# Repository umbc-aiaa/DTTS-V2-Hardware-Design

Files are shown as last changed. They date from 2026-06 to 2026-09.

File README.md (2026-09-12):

# DTTS V2

This repo houses the hardware design and associated documentation for the SUAS Dynamic Thrust Test Stand(DTTS) V2.
The new board is designed to be more intuitive to use and more robust against failures like over voltage, shorts, etc.
The V2 board also integrates all sensors and ICs in a single solution.



## System Diagram
```mermaid
graph LR;
LC[<b>Load Cell</b></br>Uses a Wheatstone Bridge to provide a differential voltage signal to the ADC.];
CS[<b>Current Sensor</b></br>Current sensing is implemented with a shunt resistor with differential input feeding into the ADC.];
VS[<b>Voltage Sensor</b></br>Voltage sensing circuit is implemented as a simple resistor voltage divider.];
ADC["<b>Analog-to-Digital Converter (ADC)</b></br>Converts single mode and differential analog signals into a digital format."];
MC[<b>ESP32 S3 WROOM 1</b></br>Controls esc for the motor, collects measurements, and communcates them over WiFi.];
ESC[<b>Electronic Speed Controller</b><br />Converts DC from battery to 3-phase AC for motor.]

GUI[<b>Front End UI</b></br>A front end GUI collects measurements and makes user interaction simple.];

LC --> ADC;
CS --> ADC;
VS --> ADC;

ADC --> MC;

MC -- PWM --> ESC;

GUI <== WiFi ==> MC;

ADC ~~~ GUI;
```

## Working Specs
- Battery Voltage $\leq$ 50 V.
- Max ESC Current $\leq$ 90 A.
- Using 6 AWG wire for battery.
- Must at minimum measure battery voltage, batter to ESC current, and Motor Thrust
- All circuitry must run off of a single battery -- the one plugged into the ESC
- Preferable to have auto-trimming and gain calibration on voltage sense circuity.

## Component Selection (Draft!)

### Power Supply
There are some different approaches to this. If we were using a seperate battery for this, then we could have just used a linear regulator, but if we want to use the motor battery, this voltage may range from 12 to 60 V. So we probably need to use a buck converter. We could also use a hybrid design (i.e. 12-60V input down to 4.5V with a buck converter and 4.5V to 3.3V with an LDO). This may complicate things a little, but it's a very good choice in terms of noise and is also fairly efficient.

1. ~~[Diodes Incorporated AP66200](https://www.diodes.com/assets/Datasheets/AP66200.pdf) Buck controller.~~
2. [TI LMR51625](https://www.ti.com/lit/ds/symlink/lmr51625.pdf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) Buck Controller (preferred).
  a. Also, if using TI ICs for power conversion, check out [Webench Designer](https://webench.ti.com/power-designer/)

**All regulated power rails must have a zener diode of appropriate voltage to pull lines down if they have too high of a voltage.**
We should run some simulations to ensure the zener diode is enough for protecting regulated lines if battery is shorted to them or if
we need to have something else. We may also want to consider adding a fuse to the power rail since the zener diode will short to ground
and pull a lot of current.

## Voltage Protection on Signal Pins
For signal pins, zener diodes may work, but there are options for more precise control like Schottkey diodes. These can also provide reverse polarity protection if configured correctly, so this is the solution we will use. Here are some options for diodes that may work. The Rohm diode has a lower forward drop, which is good for protecting against over-voltage, but it has a low reverse voltage rating which is worse for reverse-polarity protection. The opposite is true for the Toshiba diode. We may need to look for other diodes that have the adequate reverse voltage rating(60V) and a low drop(ideally $\leq$ 300mV).
1. [Toshiba CUS10S30 Schottkey Diodes](https://toshiba.semicon-storage.com/info/CUS10S30_datasheet_en_20140407.pdf?did=14077&prodName=CUS10S30) for signal over-voltage protection.\
  a. [Rohm RB520CM-60 Schottkey Diode](https://fscdn.rohm.com/en/products/databook/datasheet/discrete/diode/schottky_barrier/rb520cm-60t2r-e.pdf) Alternative to (1) with higher reverse voltage

### Analog to Digital Converter
This component converts analog voltages(i.e. voltages that are not strictly interpretted as a `0` or a `1`) into a digital format(i.e. `0`'s and `1`'s). This allows software on the esp32 to read and store analog voltages as numbers or percents and communicate these values over WiFi or another transport medium to the GUI for the user. Since we are using a load cell, this needs a sensative ADC, and hence we choose to use a 24-bit chip. These are some options worth considering:

1. [Microchip MCP3564R](https://ww1.microchip.com/downloads/aemDocuments/documents/APID/ProductDocuments/DataSheets/MCP3561_2_4R-Data-Sheet-DS200006391C.pdf) has four channels, meaning we can use this for all three sensors (battery voltage, battery current, and motor thrust).

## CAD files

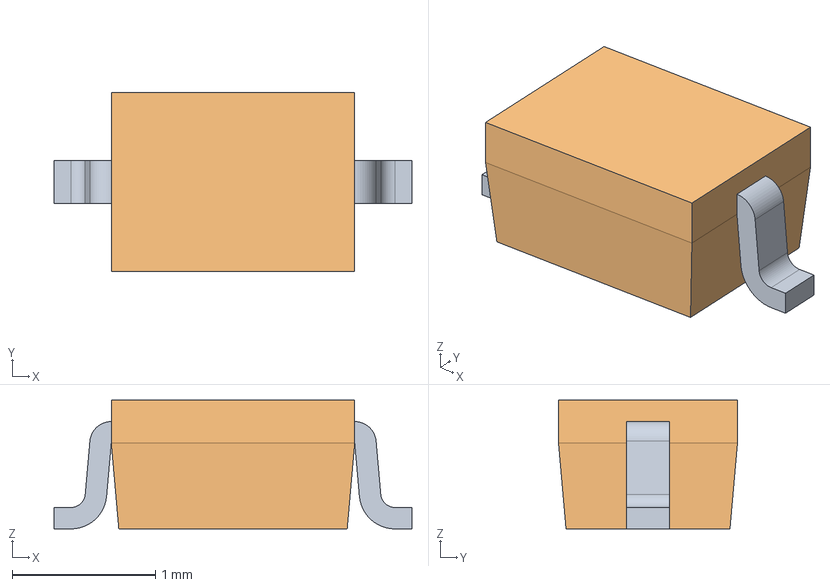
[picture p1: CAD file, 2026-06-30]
CUS520_H3F/USC-ZKN_r.stp
2.50 x 1.25 x 0.9 mm

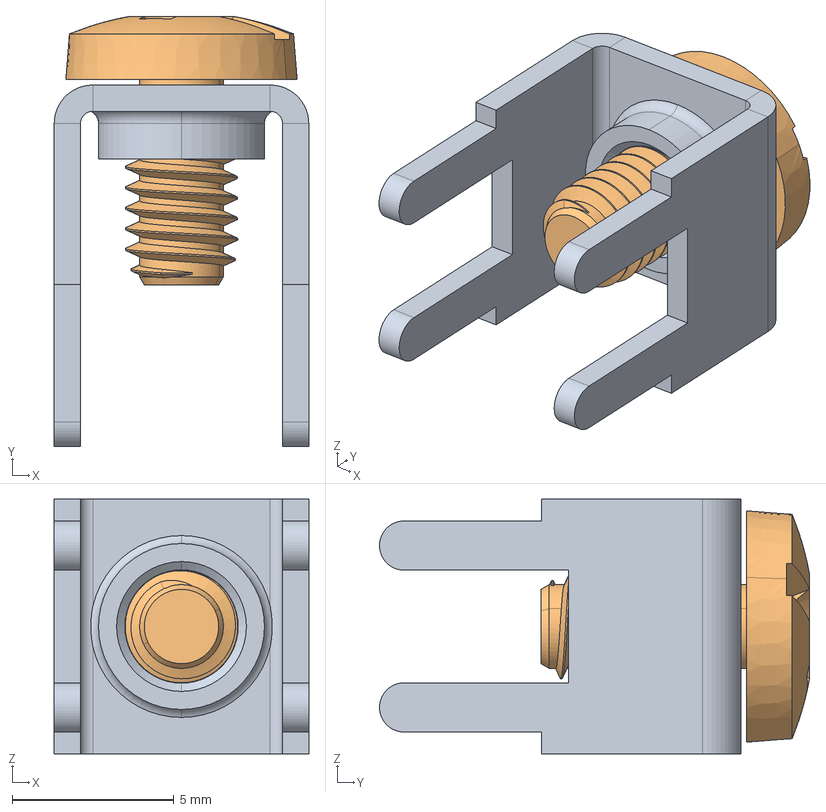
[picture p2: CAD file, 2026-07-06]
Keystone 7771-7771.step
7.87 x 13.3 x 7.87 mm

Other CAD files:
CUS520_H3F/USC-ZKN_r.stl

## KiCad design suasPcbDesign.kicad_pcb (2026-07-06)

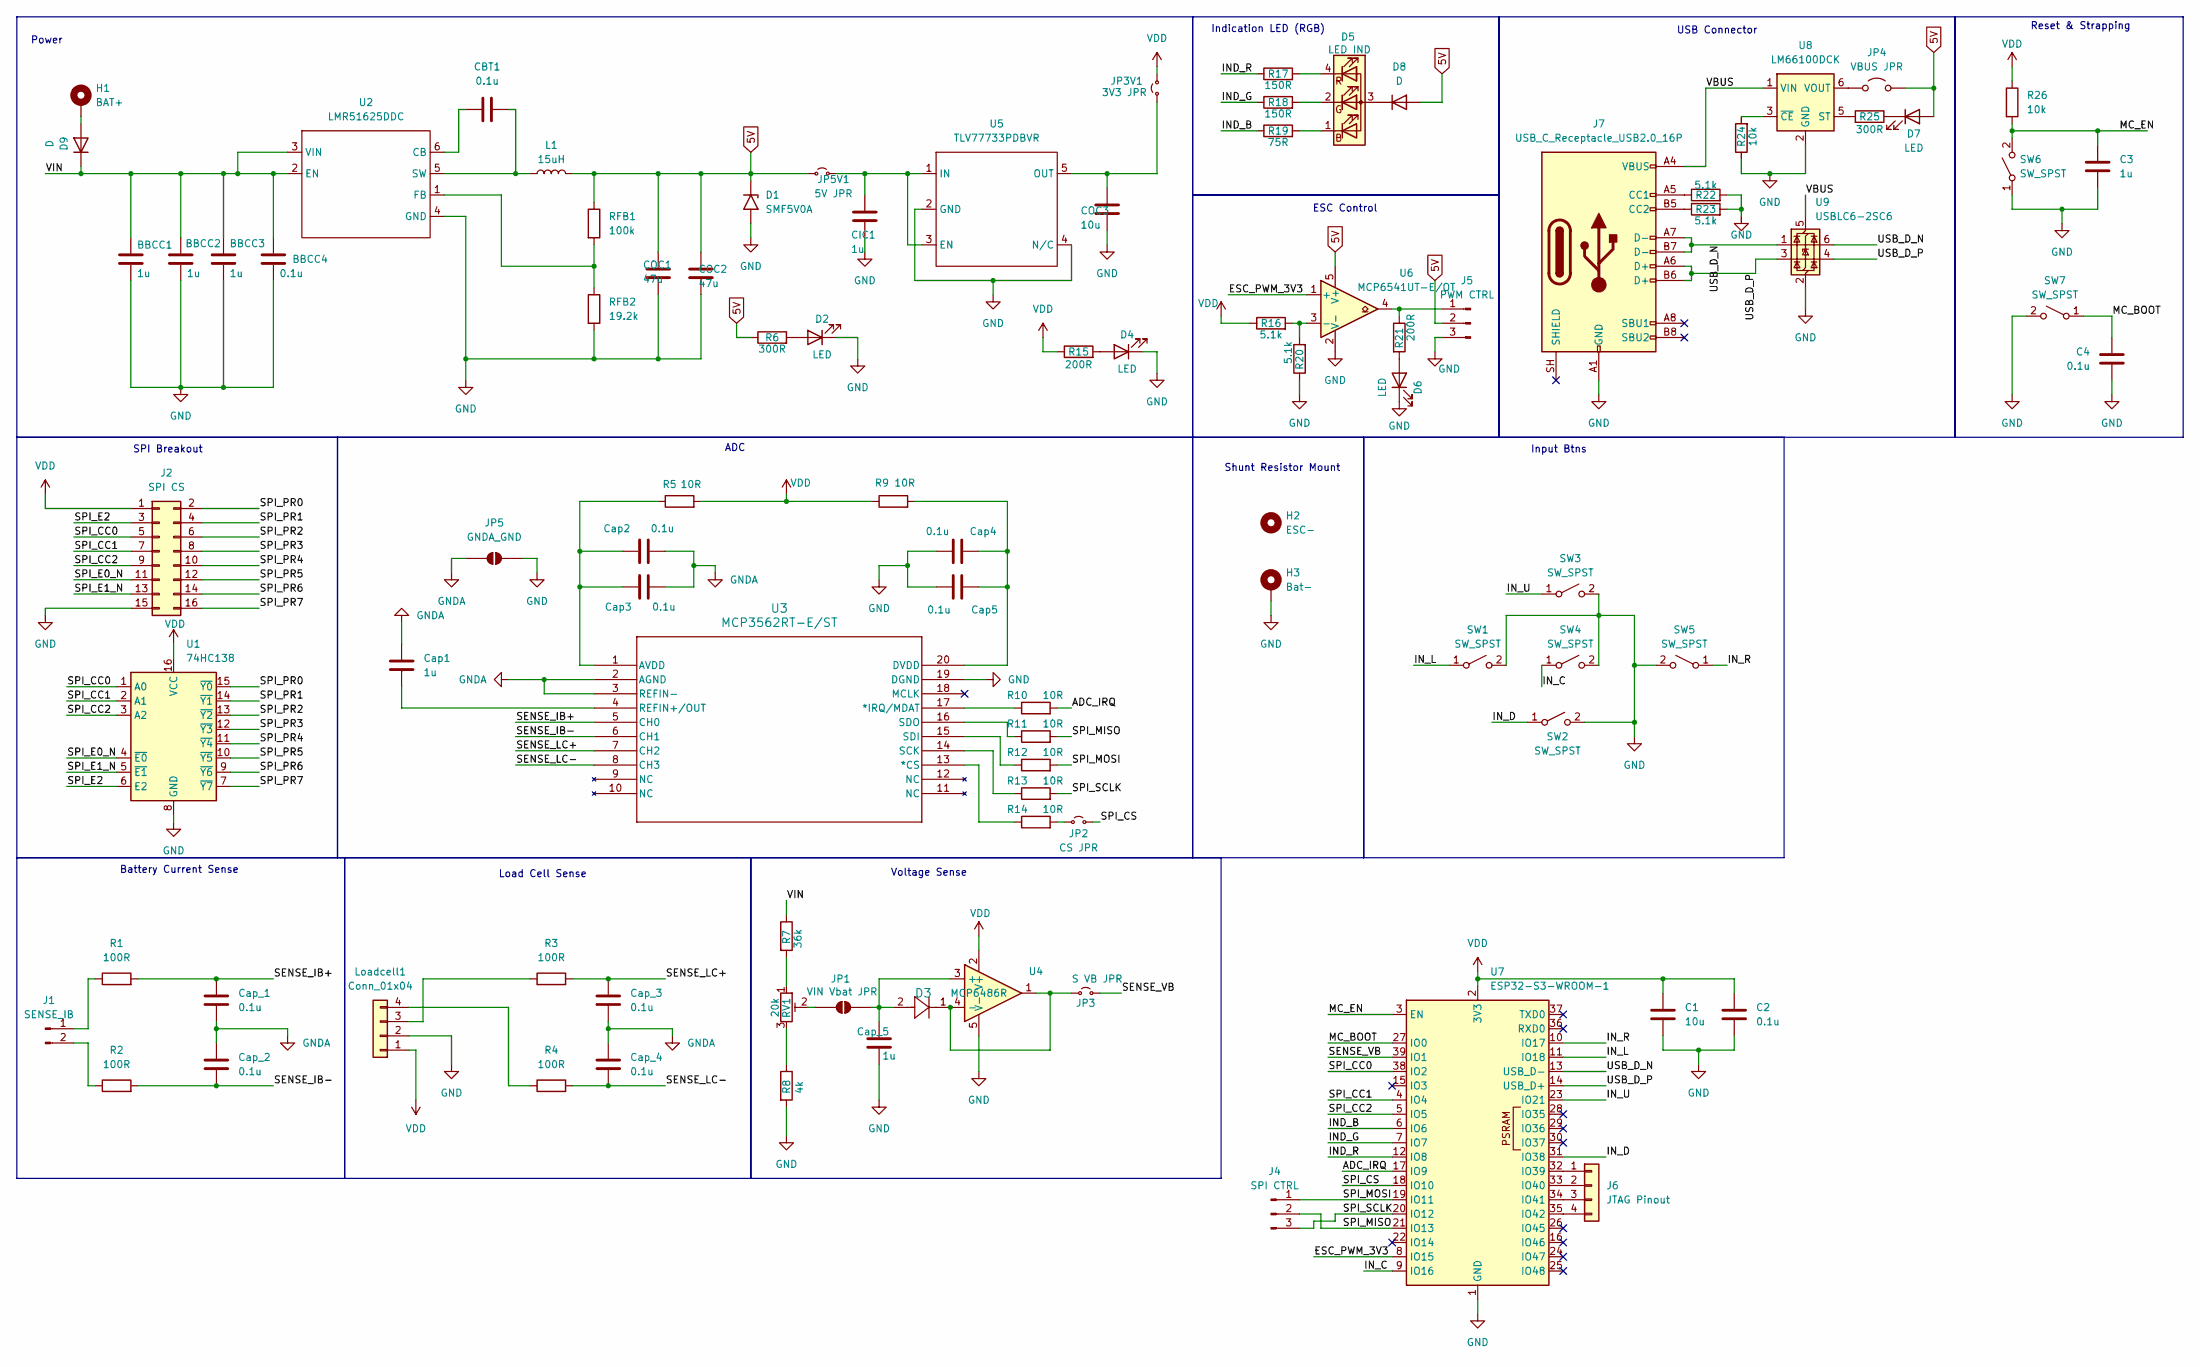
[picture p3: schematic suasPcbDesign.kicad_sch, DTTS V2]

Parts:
BBCC1, BBCC2, BBCC3: 1u; C_0603_1608Metric_Pad1.08x0.95mm_HandSolder
BBCC4: 0.1u; C_0603_1608Metric_Pad1.08x0.95mm_HandSolder
C1: 10u; C_0603_1608Metric_Pad1.08x0.95mm_HandSolder
C2, C4: 0.1u; C_0603_1608Metric_Pad1.08x0.95mm_HandSolder
C3: 1u; C_0603_1608Metric_Pad1.08x0.95mm_HandSolder
CBT1: 0.1u; C_0603_1608Metric_Pad1.08x0.95mm_HandSolder
CIC1: 1u; C_0603_1608Metric_Pad1.08x0.95mm_HandSolder
COC1, COC2: 47u; C_0603_1608Metric_Pad1.08x0.95mm_HandSolder
COC3: 10u; C_0603_1608Metric_Pad1.08x0.95mm_HandSolder
Cap1: 1u; C_0603_1608Metric_Pad1.08x0.95mm_HandSolder
Cap2, Cap3, Cap4, Cap5: 0.1u; C_0603_1608Metric_Pad1.08x0.95mm_HandSolder
Cap_1, Cap_2, Cap_3, Cap_4: 0.1u; C_0603_1608Metric_Pad1.08x0.95mm_HandSolder
Cap_5: 1u; C_0603_1608Metric_Pad1.08x0.95mm_HandSolder
D1: SMF5V0A; D_SOD-123
D2, D4, D6, D7: LED; LED_0603_1608Metric_Pad1.05x0.95mm_HandSolder
D3: CUS520_H3F; USC_TOS
D5: LED IND; LED_D5.0mm-4_RGB
D8, D9: D; D_SMA-SMB_Universal_Handsoldering
H1: BAT+; 7770 Keystone Electronics PC SCREW TERMINALS
H2: ESC-; MountingHole_6.3mm_M6_DIN965
H3: Bat-; MountingHole_6.3mm_M6_Pad_Via
J1: SENSE_IB; SolderWire-1sqmm_1x02_P5.4mm_D1.4mm_OD2.7mm
J2: SPI CS; PinHeader_2x08_P2.54mm_Vertical
J4: SPI CTRL; PinHeader_1x03_P2.54mm_Vertical
J5: PWM CTRL; PinHeader_1x03_P2.54mm_Vertical
J6: JTAG Pinout; PinHeader_1x04_P2.54mm_Vertical
J7: USB_C_Receptacle_USB2.0_16P; USB_C_Receptacle_GCT_USB4105-xx-A_16P_TopMnt_Horizontal
JP1: VIN Vbat JPR; SolderJumper-2_P1.3mm_Open_Pad1.0x1.5mm
JP2: CS JPR; TestPoint_2Pads_Pitch2.54mm_Drill0.8mm
JP3: S VB JPR; TestPoint_2Pads_Pitch2.54mm_Drill0.8mm
JP3V1: 3V3 JPR; TestPoint_2Pads_Pitch2.54mm_Drill0.8mm
JP4: VBUS JPR; TestPoint_2Pads_Pitch2.54mm_Drill0.8mm
JP5: GNDA_GND; SolderJumper-2_P1.3mm_Open_Pad1.0x1.5mm
JP5V1: 5V JPR; TestPoint_2Pads_Pitch2.54mm_Drill0.8mm
L1: 15uH; L_APV_APH1050
Loadcell1: Conn_01x04; PinHeader_1x04_P2.54mm_Vertical
R1, R2, R3, R4: 100R; R_0603_1608Metric_Pad0.98x0.95mm_HandSolder
R5, R9, R10, R11, R12, R13, R14: 10R; R_0603_1608Metric_Pad0.98x0.95mm_HandSolder
R6, R25: 300R; R_0603_1608Metric_Pad0.98x0.95mm_HandSolder
R7: 36k; R_0603_1608Metric_Pad0.98x0.95mm_HandSolder
R8: 4k; R_0603_1608Metric_Pad0.98x0.95mm_HandSolder
R15, R21: 200R; R_0603_1608Metric_Pad0.98x0.95mm_HandSolder
R16, R20, R22, R23: 5.1k; R_0603_1608Metric_Pad0.98x0.95mm_HandSolder
R17, R18: 150R; R_0603_1608Metric_Pad0.98x0.95mm_HandSolder
R19: 75R; R_0603_1608Metric_Pad0.98x0.95mm_HandSolder
R24, R26: 10k; R_0603_1608Metric_Pad0.98x0.95mm_HandSolder
RFB1: 100k; R_0603_1608Metric_Pad0.98x0.95mm_HandSolder
RFB2: 19.2k; R_0603_1608Metric_Pad0.98x0.95mm_HandSolder
RV1: 20k; Potentiometer_Bourns_3386P_Vertical
SW1, SW2, SW3, SW4, SW5, SW6, SW7: SW_SPST; SW_PUSH_1P1T_6x3.5mm_H4.3_APEM_MJTP1243
U1: 74HC138; TSSOP-16_4.4x5mm_P0.65mm
U2: LMR51625DDC; TSOT-23-6_HandSoldering
U3: MCP3562RT-E/ST; TSSOP-20_4.4x6.5mm_P0.65mm
U4: MCP6486R; SOT-23-5_HandSoldering
U5: TLV77733PDBVR; SOT-23-5_HandSoldering
U6: MCP6541UT-E/OT; SOT-23-5_HandSoldering
U7: ESP32-S3-WROOM-1
U8: LM66100DCK; SOT-363_SC-70-6
U9: USBLC6-2SC6; SOT-23-6

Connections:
5V: COC1.1, COC2.1, D1.1 (A1), D7.2 (A), D8.2 (A), J5.2, JP4.2 (B), JP5V1.1 (A), L1.2, R6.1, RFB1.1, U6.5 (V+)
/ADC_IRQ: R10.2, U7.17 (IO9)
/ESC_PWM_3V3: U6.1 (+), U7.8 (IO15)
/IND_B: R19.1, U7.6 (IO6)
/IND_G: R18.1, U7.7 (IO7)
/IND_R: R17.1, U7.12 (IO8)
/IN_C: SW4.1 (A), U7.9 (IO16)
/IN_D: SW2.1 (A), U7.31 (IO38)
/IN_L: SW1.1 (A), U7.11 (IO18)
/IN_R: SW5.1 (A), U7.10 (IO17)
/IN_U: SW3.1 (A), U7.23 (IO21)
/MC_BOOT: C4.1, SW7.1 (A), U7.27 (IO0)
/MC_EN: C3.1, R26.2, SW6.2 (B), U7.3 (EN)
/SENSE_IB+: Cap_1.1, R1.2, U3.5 (CH0)
/SENSE_IB-: Cap_2.2, R2.2, U3.6 (CH1)
/SENSE_LC+: Cap_3.1, R3.2, U3.7 (CH2)
/SENSE_LC-: Cap_4.2, R4.2, U3.8 (CH3)
/SENSE_VB: JP3.2 (B), U7.39 (IO1)
/SPI_CC0: J2.5, U1.1 (A0), U7.38 (IO2)
/SPI_CC1: J2.7, U1.2 (A1), U7.4 (IO4)
/SPI_CC2: J2.9, U1.3 (A2), U7.5 (IO5)
/SPI_CS: JP2.2 (B), U7.18 (IO10)
/SPI_E0_N: J2.11, U1.4 (~E0)
/SPI_E1_N: J2.13, U1.5 (~E1)
/SPI_E2: J2.3, U1.6 (E2)
/SPI_MISO: J4.2, R11.2, U7.21 (IO13)
/SPI_MOSI: J4.1, R12.2, U7.19 (IO11)
/SPI_PR0: J2.2, U1.15 (~Y0)
/SPI_PR1: J2.4, U1.14 (~Y1)
/SPI_PR2: J2.6, U1.13 (~Y2)
/SPI_PR3: J2.8, U1.12 (~Y3)
/SPI_PR4: J2.10, U1.11 (~Y4)
/SPI_PR5: J2.12, U1.10 (~Y5)
/SPI_PR6: J2.14, U1.9 (~Y6)
/SPI_PR7: J2.16, U1.7 (~Y7)
/SPI_SCLK: J4.3, R13.2, U7.20 (IO12)
/USB_D_N: J7.A7 (D-), J7.B7 (D-), U7.13 (USB_D-), U9.1 (I/O1), U9.6 (I/O1)
/USB_D_P: J7.A6 (D+), J7.B6 (D+), U7.14 (USB_D+), U9.3 (I/O2), U9.4 (I/O2)
/VBUS: J7.A4 (VBUS), J7.A9 (VBUS), J7.B4 (VBUS), J7.B9 (VBUS), U8.1 (VIN), U9.5 (VBUS)
/VIN: BBCC1.1, BBCC2.1, BBCC3.1, BBCC4.1, D9.1 (K), R7.1, U2.2 (EN), U2.3 (VIN)
GND: BBCC1.2, BBCC2.2, BBCC3.2, BBCC4.2, C1.2, C2.2, C3.2, C4.2, CIC1.2, COC1.2, COC2.2, COC3.2, Cap4.2, Cap5.2, Cap_5.2, D1.2 (A2), D2.1 (K), D4.1 (K), D6.1 (K), H3.1 (1_1), J2.15, J5.3, J7.A1 (GND), J7.A12 (GND), J7.B1 (GND), J7.B12 (GND), JP5.2 (B), Loadcell1.2, R8.2, R20.1, R22.2, R23.2, R24.1, RFB2.2, SW1.2 (B), SW2.2 (B), SW3.2 (B), SW4.2 (B), SW5.2 (B), SW6.1 (A), SW7.2 (B), U1.8 (GND), U2.4 (GND), U3.19 (DGND), U4.5 (V-), U5.2 (GND), U5.4 (N/C), U6.2 (V-), U7.1 (GND), U7.40 (GND), U7.41 (GND), U8.2 (GND), U9.2 (GND)
GNDA: Cap1.2, Cap2.2, Cap3.2, Cap_1.2, Cap_2.1, Cap_3.2, Cap_4.1, JP5.1 (A), U3.2 (AGND), U3.3 (REFIN-)
unnamed: D2.2 (A), R6.2
unnamed: D4.2 (A), R15.2
unnamed: D5.3 (A), D8.1 (K)
unnamed: D5.1 (BK), R19.2
unnamed: D5.2 (GK), R18.2
unnamed: D5.4 (RK), R17.2
unnamed: D6.2 (A), R21.2
unnamed: D7.1 (K), R25.1
unnamed: D9.2 (A), H1.1 (1_1)
unnamed: J1.1, R1.1
unnamed: J1.2, R2.1
unnamed: J5.1, R21.1, U6.4
unnamed: J6.1, U7.32 (IO39)
unnamed: J6.2, U7.33 (IO40)
unnamed: J6.3, U7.34 (IO41)
unnamed: J6.4, U7.35 (IO42)
unnamed: J7.A5 (CC1), R22.1
unnamed: J7.B5 (CC2), R23.1
unnamed: JP1.1 (A), RV1.2
unnamed: Cap_5.1, D3.2, JP1.2 (B), U4.3 (+)
unnamed: JP2.1 (A), R14.2
unnamed: D3.1, JP3.1 (A), U4.1, U4.4 (-)
unnamed: COC3.1, JP3V1.1 (A), U5.5 (OUT)
unnamed: JP4.1 (A), U8.6 (VOUT)
unnamed: CIC1.1, JP5V1.2 (B), U5.1 (IN), U5.3 (EN)
unnamed: Loadcell1.3, R3.1
unnamed: Loadcell1.4, R4.1
unnamed: R7.2, RV1.1
unnamed: R8.1, RV1.3
unnamed: CBT1.1, U2.6 (CB)
unnamed: RFB1.2, RFB2.1, U2.1 (FB)
unnamed: CBT1.2, L1.1, U2.5 (SW)
unnamed: R14.1, U3.13 (*CS)
unnamed: R10.1, U3.17 (*IRQ/MDAT)
unnamed: Cap2.1, Cap3.1, R5.1, U3.1 (AVDD)
unnamed: Cap4.1, Cap5.1, R9.2, U3.20 (DVDD)
unnamed: Cap1.1, U3.4 (REFIN+/OUT)
unnamed: R13.1, U3.14 (SCK)
unnamed: R12.1, U3.15 (SDI)
unnamed: R11.1, U3.16 (SDO)
unnamed: R16.2, R20.2, U6.3 (-)
unnamed: R25.2, U8.5 (ST)
unnamed: R24.2, U8.3 (~CE)
VDD: C1.1, C2.1, J2.1, JP3V1.2 (B), Loadcell1.1, R5.2, R9.1, R15.1, R16.1, R26.1, U1.16 (VCC), U4.2 (V+), U7.2 (3V3)

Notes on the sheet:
SPI Breakout
Reset & Strapping
Voltage Sense
ESC Control
Shunt Resistor Mount
Load Cell Sense
Input Btns
Battery Current Sense
Power
Indication LED (RGB)
ADC
USB Connector

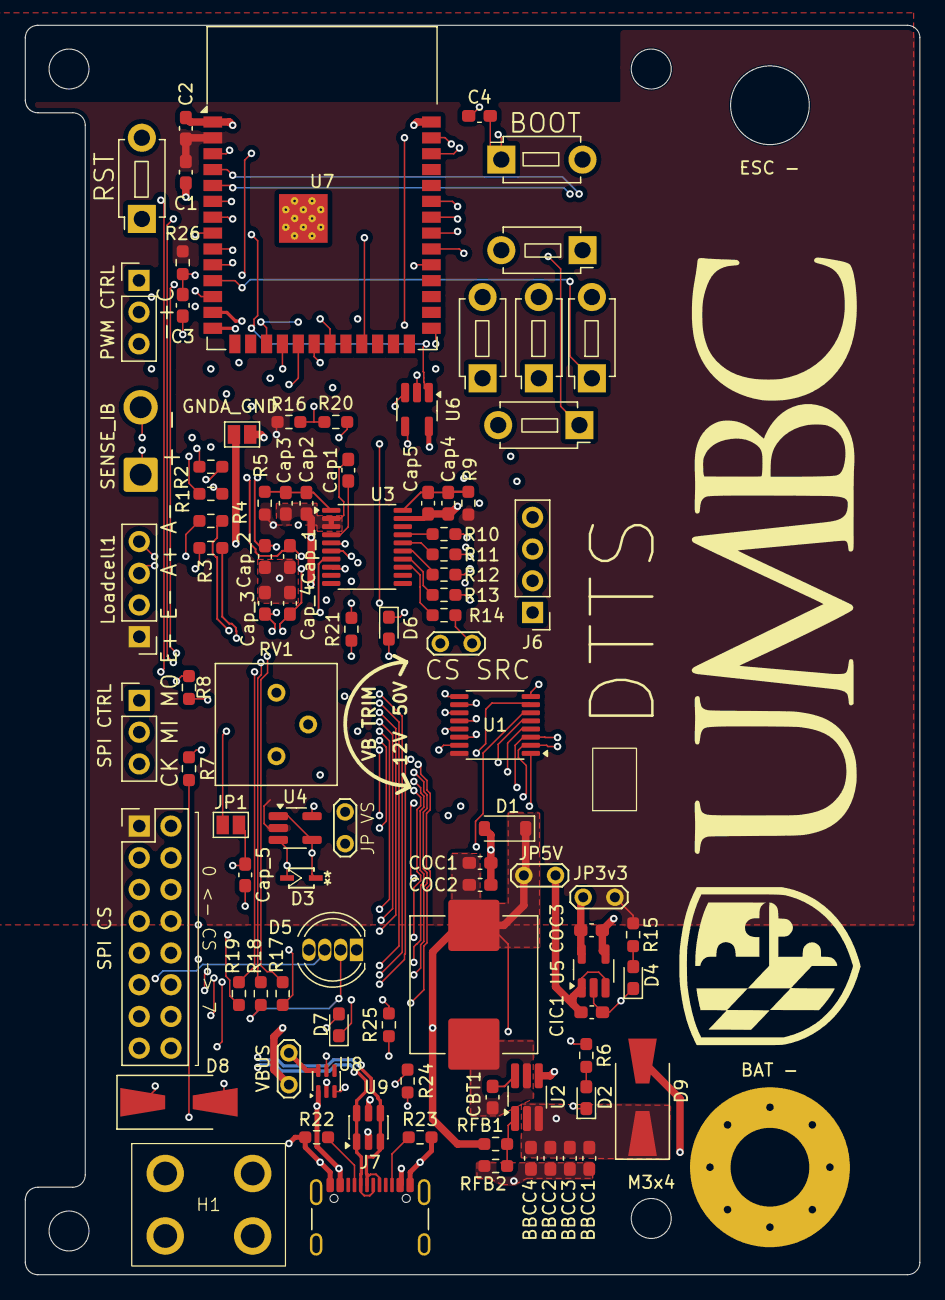
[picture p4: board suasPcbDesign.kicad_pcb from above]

Board: 4 copper layers, 71.6 x 100.0 mm, 99 parts (0 on the bottom side), 86 nets.

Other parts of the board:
M3x1, M3x2, M3x3, M3x4: MountingHole_3.2mm_M3

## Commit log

2026-04-20 added buck converter schematic
    [DTTS V2 Hardware.kicad_pcb, DTTS V2 Hardware.kicad_sch, suasPcbDesign.kicad_sch]
2026-04-21 added LDO and microcontroller
    [suasPcbDesign.kicad_pcb, suasPcbDesign.kicad_sch]
2026-04-21 added in zener diode
    [suasPcbDesign.kicad_sch]
2026-04-28 Added voltage divider
    [suasPcbDesign.kicad_sch]
2026-04-28 Fixed voltage divider and added power to ADC
    [suasPcbDesign.kicad_sch]
2026-04-28 added current sensor, finished ADC implementation, and added a battery symbol
    [suasPcbDesign.kicad_sch]
2026-04-29 added load sensor
    [suasPcbDesign.kicad_sch]
2026-04-29 added LCD display
    [suasPcbDesign.kicad_sch]
2026-05-07 added lcd display pins
    [suasPcbDesign.kicad_sch]
2026-05-08 added footprints to IC's
    [suasPcbDesign.kicad_sch]
2026-05-09 added footprints
    [suasPcbDesign.kicad_sch]
2026-05-23 corrected footprints with parts chosen from digikey
    [suasPcbDesign.kicad_pcb, suasPcbDesign.kicad_sch]
2026-06-07 configured board set up and rearranged pcb layout
    [suasPcbDesign.kicad_pcb]
2026-06-29 clean up design
    [suasPcbDesign.kicad_sch]
2026-06-29 Add voltage protection circuitry
    [suasPcbDesign.kicad_sch]
2026-06-29 Add indication lights
    [suasPcbDesign.kicad_pcb, suasPcbDesign.kicad_sch]
2026-06-29 Fix LED Type
    [suasPcbDesign.kicad_sch]
2026-06-30 Simplify voltage clamping circuit for voltage sensor
    [USC-ZKN_r.stl, USC-ZKN_r.stp, suasPcbDesign.kicad_sch]
2026-06-30 Organize schematic
    [suasPcbDesign.kicad_sch]
2026-06-30 Replace trim pot
    [suasPcbDesign.kicad_sch]
2026-06-30 Add decoupling caps to esp32 s3
    [suasPcbDesign.kicad_sch]
2026-07-01 PCB schematic ready to layout
    [suasPcbDesign.kicad_sch]
2026-07-01 Fix fotprints
    [suasPcbDesign.kicad_sch]
2026-07-01 Do the layout
    [suasPcbDesign.kicad_pcb, suasPcbDesign.kicad_sch]
2026-07-01 Add logo
    [suasPcbDesign.kicad_pcb]
2026-07-01 Change to 4 mounting hole design
    [suasPcbDesign.kicad_pcb]
2026-07-01 Add Battery and ESC negative terminal labels
    [suasPcbDesign.kicad_pcb]
2026-07-01 Update to use tht led
    [suasPcbDesign.kicad_pcb, suasPcbDesign.kicad_sch]
2026-07-01 Fix PCB size
    [suasPcbDesign.kicad_pcb]
2026-07-02 Clean up silscreen notes
    [suasPcbDesign.kicad_pcb]
2026-07-03 Change resistor value to 100R instead of 50
    [suasPcbDesign.kicad_pcb, suasPcbDesign.kicad_sch]
2026-07-05 Add reverse polarity diode and edit resistor vals
    [suasPcbDesign.kicad_pcb, suasPcbDesign.kicad_sch]
2026-07-05 Make silkscreen annotation for batt wire visible
    [suasPcbDesign.kicad_pcb]
2026-07-06 Add new comparator
    [suasPcbDesign.kicad_pcb, suasPcbDesign.kicad_sch]
2026-07-06 Update part value for comparator
    [suasPcbDesign.kicad_pcb, suasPcbDesign.kicad_sch]
2026-07-06 Fix diode position
    [suasPcbDesign.kicad_pcb, suasPcbDesign.kicad_sch]
2026-07-06 Include battery terminal in BOM
    [suasPcbDesign.kicad_pcb, suasPcbDesign.kicad_sch]
2026-07-06 Add battery screw terminal model
    [Keystone 7771-7771.step, suasPcbDesign.kicad_pcb]
2026-07-06 Add batt voltage trim guides on silkscreen
    [suasPcbDesign.kicad_pcb]
